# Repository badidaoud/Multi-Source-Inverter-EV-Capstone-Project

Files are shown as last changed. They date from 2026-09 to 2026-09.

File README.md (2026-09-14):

# Multi-Source Inverter (MSI) for Electric Vehicles

A senior capstone project (Ontario Tech University, Electrical Engineering, 2025 to 2026) that designs and prototypes a novel multi-source inverter: a single power electronics board that combines two DC inputs (for example a battery and a solar/auxiliary source) and drives a three-phase AC motor, without the extra switch count that typical multi-source topologies need.

**Team:** Emmanuel Ita, Jack Flann, Dorsheed Abdalla, Badi Daoud
**Project Coordinator:** Dr. Mohamed Z. Youssef, Ontario Tech University

> This repository is my personal, individually maintained record of a four-person team capstone. It documents the project in full and credits every teammate's contribution; it is not a claim of solo authorship. The team's original working repository, maintained by a teammate, is linked in [Attribution](#attribution-and-original-repository) below.

## Table of Contents

- [Problem Statement](#problem-statement)
- [Existing Solutions](#existing-solutions)
- [Project Objectives](#project-objectives)
- [Design Process](#design-process)
- [Proposed Design](#proposed-design)
- [Hardware and Schematics](#hardware-and-schematics)
- [Final Product](#final-product)
- [Video Demos](#video-demos)
- [Testing and Results](#testing-and-results)
- [Challenges and Root Cause Analysis](#challenges-and-root-cause-analysis)
- [My Contributions](#my-contributions)
- [Project Timeline](#project-timeline)
- [Repository Contents](#repository-contents)
- [Attribution and Original Repository](#attribution-and-original-repository)

## Problem Statement

Electric vehicle inverters today face real limits on efficiency, size, and flexibility:

- Most EV traction inverters run on a single DC source, which restricts controllability and limits adaptability across operating conditions.
- Efficiency drops significantly at partial loads, which is most of real-world driving, directly impacting vehicle range.
- Modern EV systems increasingly need to combine multiple DC sources (battery cells, PV modules, auxiliary supplies) and reconfigure them dynamically.
- Existing multi-source inverter (MSI) topologies in the literature solve this, but usually at the cost of high switch counts, added control circuitry, and a larger form factor.

The goal of this project was to design an MSI that keeps the benefits of multi-source operation (dynamic voltage combining, source flexibility) while cutting down the component count, board footprint, and cost that usually come with it.

## Existing Solutions

We reviewed the landscape before designing our own approach:

- Conventional 2-level and 3-level NPC inverters with a single DC input: good performance, but high switching losses and no source flexibility.
- PWM/SPWM control: simple and widely used, but DC-bus utilization tops out around 78% with significant harmonic distortion.
- SVPWM control: better DC-bus utilization (over 90%) and lower distortion, but still tied to a single fixed-voltage DC link.
- Two-input MSI topologies from the literature: allow dynamic voltage combining, but require many switches, which increases complexity, size, and cost.
- Source-combination strategies each have a tradeoff: parallel combination needs identical sources and limits voltage flexibility, series combination risks source imbalance and voltage jumps, and switched MSI structures add control complexity and don't scale well past two sources.

No market solution currently exists for this exact combination of goals; reconfigurable EV battery packs exist, but they switch a single battery system between series and parallel, not multiple independent sources into one inverter stage.

## Project Objectives

Six requirements, tied directly to the problem above, drove every design decision:

- Design a novel multi-source input stage
- Minimize component count
- Develop a PCB with a minimal footprint
- Meet safety requirements
- Meet a $800 budget
- Minimize harmonic distortion

## Design Process

We followed an iterative engineering workflow: problem definition, requirement specification, research on existing solutions, concept generation, PSIM simulation, conceptual system design, PCB layout, firmware design, and testing and evaluation, cycling back through simulation and system design as results came in.

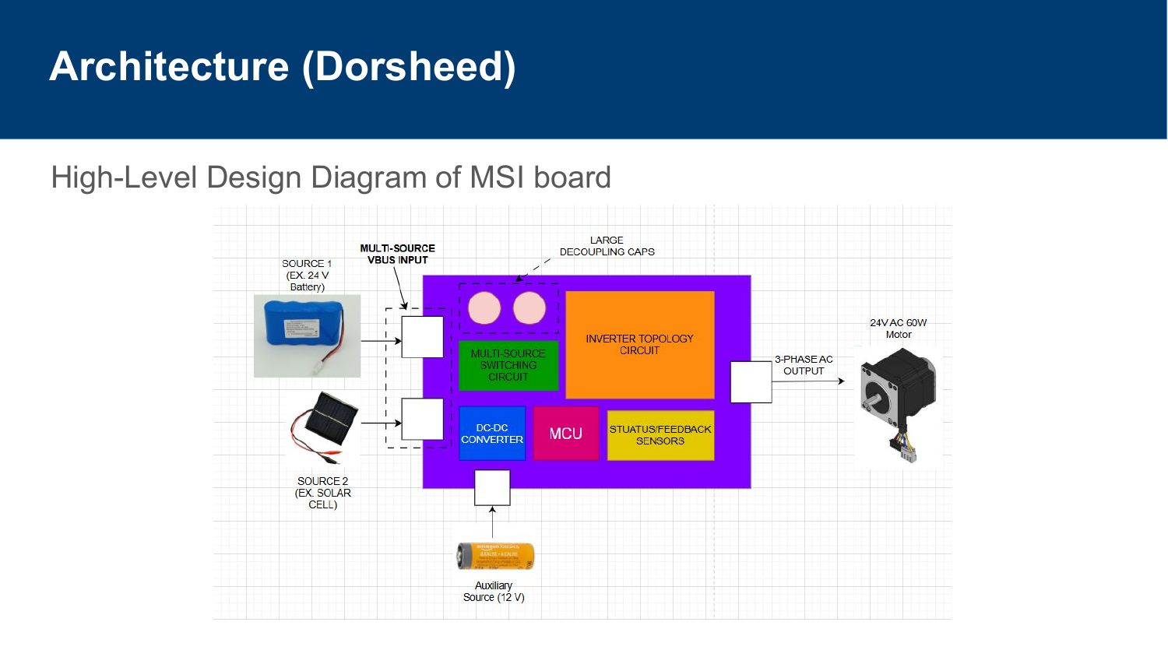
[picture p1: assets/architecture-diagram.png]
Design process flowchart

*High-level design diagram of the MSI board: two DC sources plus an auxiliary 12V supply feed a multi-source switching circuit and DC-DC converter, controlled by an STM32 MCU, driving a 2-level inverter topology out to a three-phase AC motor.*

Field-Oriented Control (FOC) was chosen as the motor control strategy: a closed-loop scheme that maximizes the motor's quadrature (rotational) force by continuously measuring output currents and rotor position and adjusting switching accordingly.

## Proposed Design

Our novel MSI design combines two DC battery inputs in parallel through a switched front end, which:

- Merges multiple DC inputs safely into a shared DC bus (12, 24, or 36V depending on configuration)
- Minimizes component count relative to literature MSI topologies
- Supports multiple voltage levels and can scale up toward a full-size system
- Uses diodes in the prototype (for a full-scale version, these would be replaced with actively controlled IGBTs or SiC MOSFETs)

The main design risks we identified going in were shoot-through during switching (which can cause extensive damage) and the need for tight current control during source-mode transitions, both of which turned out to matter later during hardware testing (see [Challenges and Root Cause Analysis](#challenges-and-root-cause-analysis)).

## Hardware and Schematics

The board is organized into six subsections: multi-source input switching, auxiliary input power, a DC-DC/voltage regulation stage, an STM32/ESP32-class microcontroller for control, a 2-level inverter topology stage (gate drivers plus MOSFETs), and feedback sensors (current, voltage, and speed sensing) for closed-loop control. The full KiCad source for each sheet below lives in [`hardware/kicad/`](hardware/kicad/); everything here was individually recreated in KiCad after the original board's PCB order came back defective (see [Challenges and Root Cause Analysis](#challenges-and-root-cause-analysis)).

<table>
<tr>
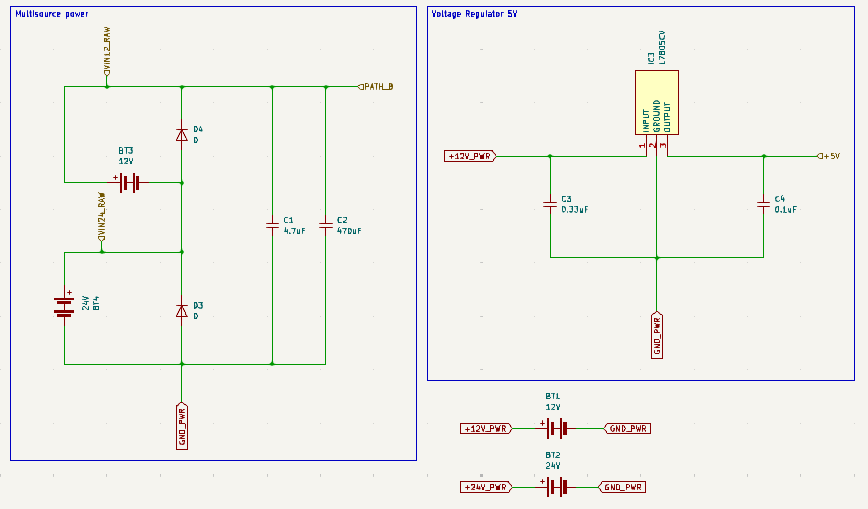
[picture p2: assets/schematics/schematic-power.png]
Multi-source power and 5V voltage regulator schematic
<td></td>
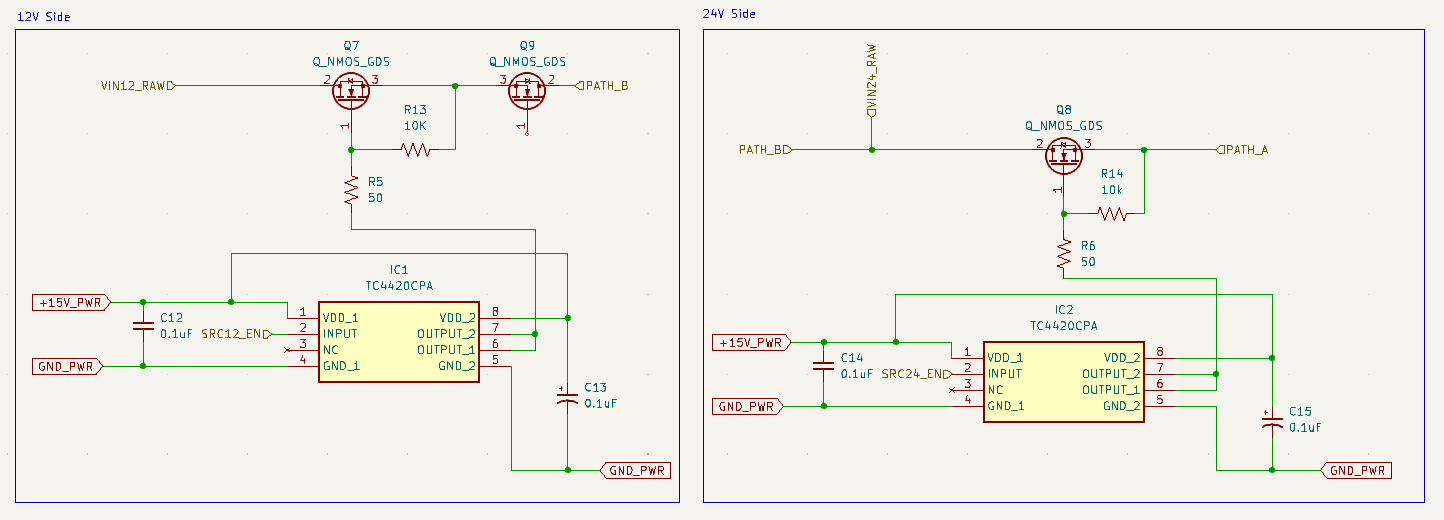
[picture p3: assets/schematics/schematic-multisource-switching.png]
Multi-source path switching schematic
<td></td>
</tr>
<tr>
<td align="center"><em>Power sheet: 12V/24V multi-source battery inputs and 5V linear regulator (<a href="hardware/kicad/Power.kicad_sch">Power.kicad_sch</a>)</em></td>
<td align="center"><em>Multi-source path switching (12V/24V side MOSFET switching into PATH_A/PATH_B). Source file for this sheet was not part of this export; screenshot only.</em></td>
</tr>
<tr>
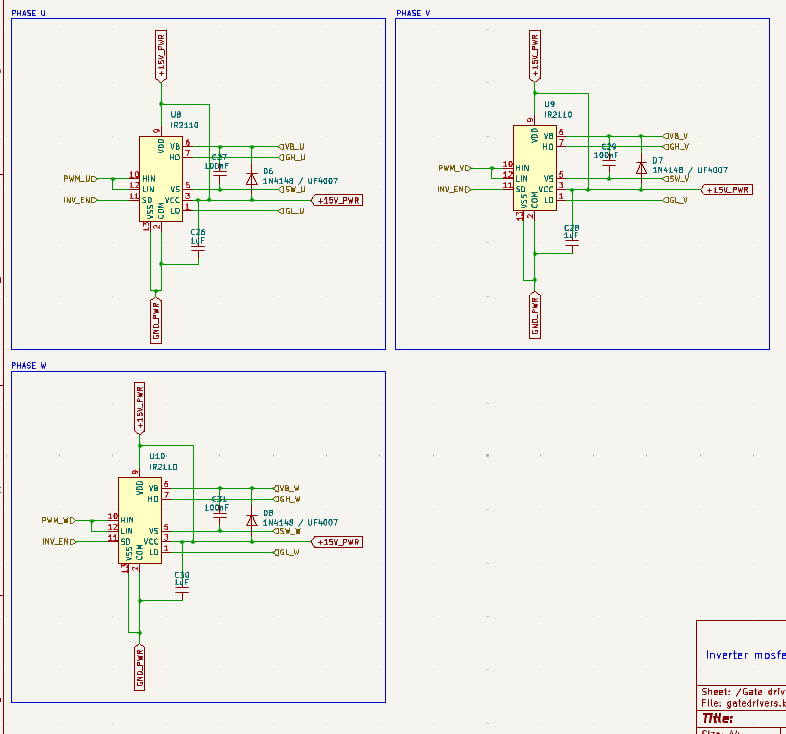
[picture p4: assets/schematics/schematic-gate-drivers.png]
Gate driver schematic
<td></td>
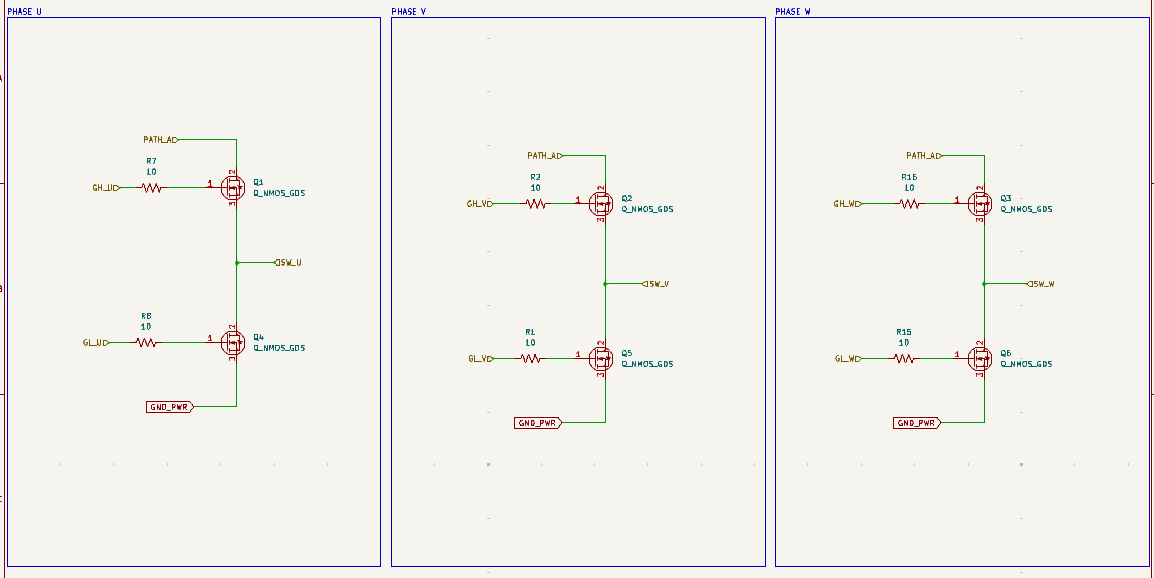
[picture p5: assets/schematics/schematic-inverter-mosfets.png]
Inverter MOSFET stage schematic
<td></td>
</tr>
<tr>
<td align="center"><em>Gate drivers: IR2110/IR2LLO high/low-side drivers per phase (<a href="hardware/kicad/gatedrivers.kicad_sch">gatedrivers.kicad_sch</a>)</em></td>
<td align="center"><em>2-level inverter MOSFET stage, phases U/V/W (<a href="hardware/kicad/inverters.kicad_sch">inverters.kicad_sch</a>)</em></td>
</tr>
<tr>
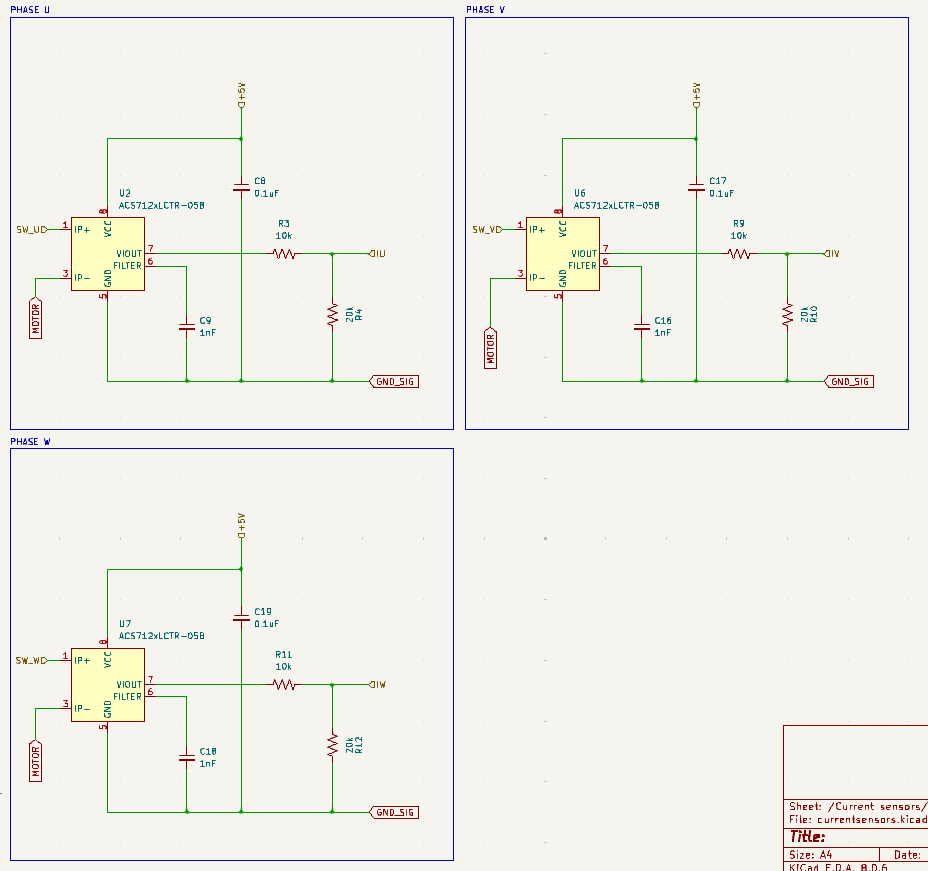
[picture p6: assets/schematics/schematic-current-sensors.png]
Current sensor schematic
<td></td>
<td>Motor connector schematic</td>
</tr>
<tr>
<td align="center"><em>Per-phase current sensing with ACS712 Hall-effect sensors (<a href="hardware/kicad/currentsensors.kicad_sch">currentsensors.kicad_sch</a>)</em></td>
<td align="center"><em>Motor output connector (<a href="hardware/kicad/motor.kicad_sch">motor.kicad_sch</a>)</em></td>
</tr>
</table>

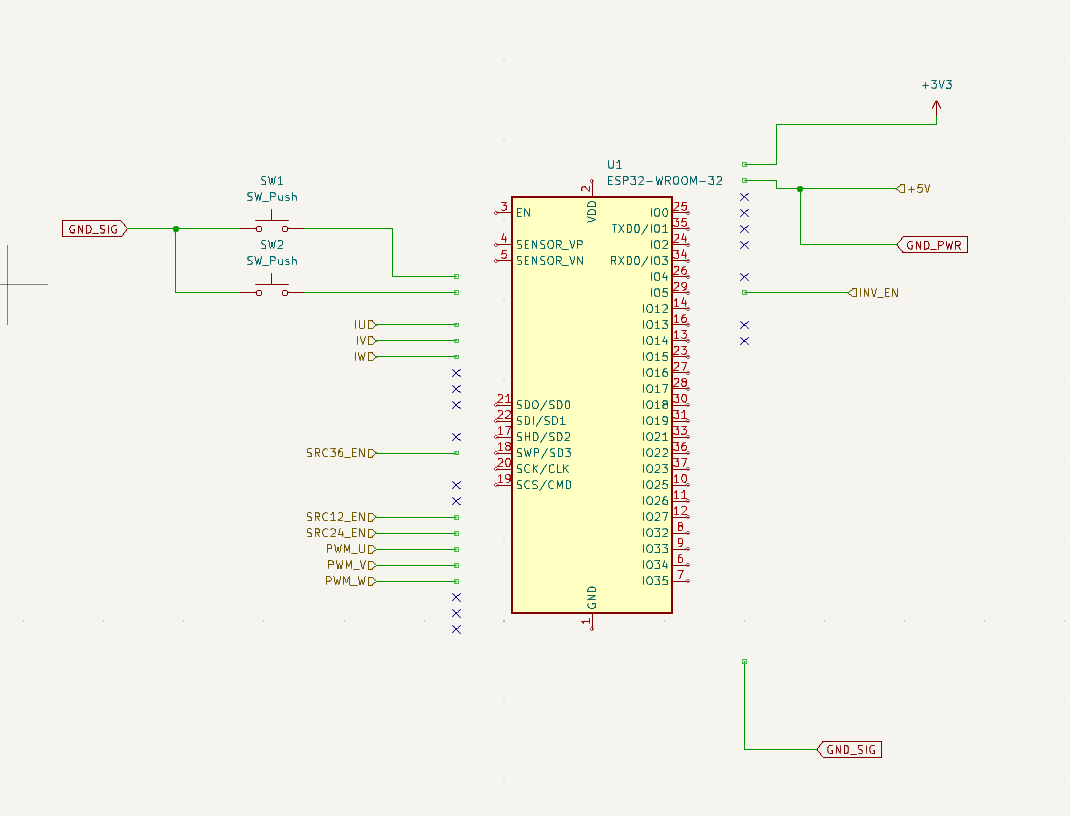
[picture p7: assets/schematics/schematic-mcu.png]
MCU schematic


*Microcontroller sheet (<a href="hardware/kicad/MCU.kicad_sch">MCU.kicad_sch</a>). This sheet was not finished by the end of the capstone; it's included as a work in progress, not a completed design.*

The top-level sheet tying everything together is [`hardware/kicad/MSI.kicad_sch`](hardware/kicad/MSI.kicad_sch). Note the PCB layout itself (copper routing, footprints) was not completed in KiCad due to time constraints; the [Final Product](#final-product) PCB images below are from the original Altium-based board.

Additional schematic sections (connectors, DC-DC converter details) are also captured slide-by-slide in the demo presentation under [`docs/presentations/`](docs/presentations/).

## Final Product

<table>
<tr>
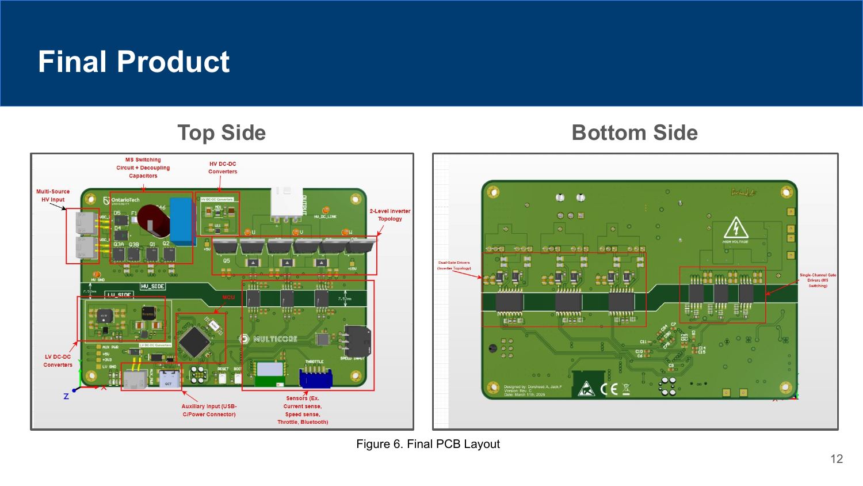
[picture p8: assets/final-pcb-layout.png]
Final PCB layout, top and bottom
<td></td>
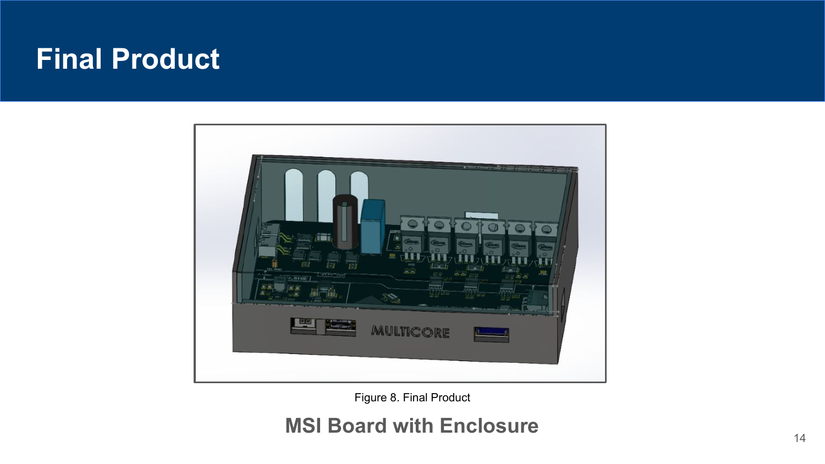
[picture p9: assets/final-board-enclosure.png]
Final MSI board with enclosure
<td></td>
</tr>
<tr>
<td align="center"><em>Final PCB layout (top and bottom copper)</em></td>
<td align="center"><em>Final board with enclosure, ready for demo</em></td>
</tr>
</table>

## Video Demos

<table>
<tr>
<td><a href="https://youtu.be/wHL-Usw2PE0">Capstone working demo video</a></td>
<td><a href="https://www.youtube.com/watch?v=NoywARZFs50">KiCad prototype walkthrough video</a></td>
</tr>
<tr>
<td align="center"><a href="https://youtu.be/wHL-Usw2PE0">Team capstone working demo</a></td>
<td align="center"><a href="https://www.youtube.com/watch?v=NoywARZFs50">My individual KiCad prototype walkthrough</a></td>
</tr>
</table>

## Testing and Results

Testing moved from individual component validation up to full integration:

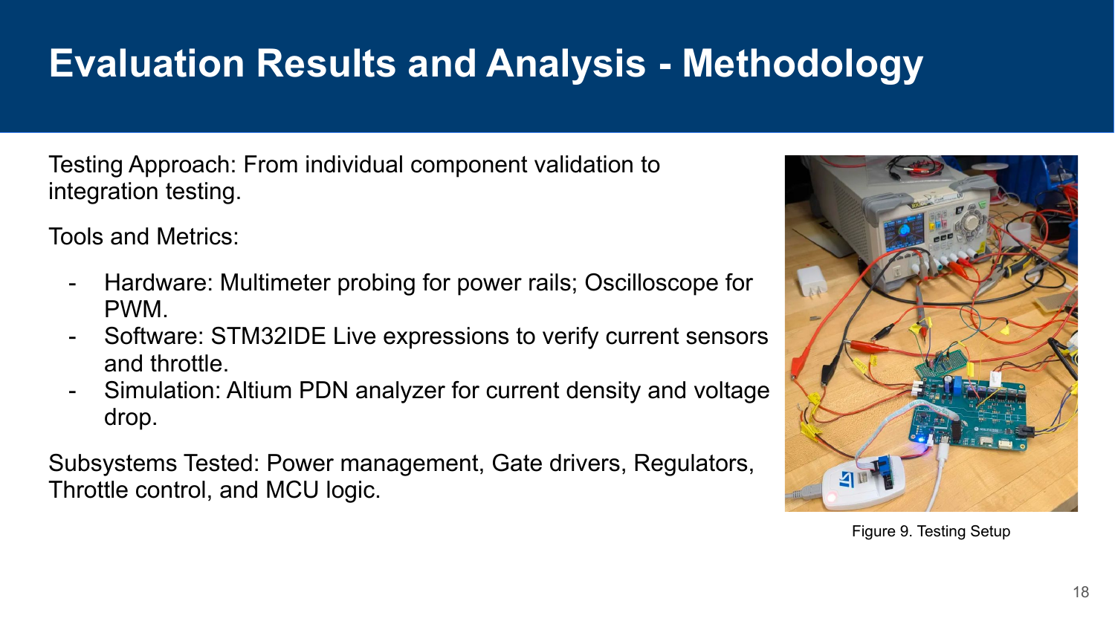
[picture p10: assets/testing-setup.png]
Testing setup

*Bench testing setup: multimeter probing on power rails, oscilloscope on PWM outputs, STM32IDE live expressions for current sensors and throttle, and Altium's PDN analyzer for current density and voltage drop in simulation.*

Being upfront about the outcome is part of the point of documenting this project:

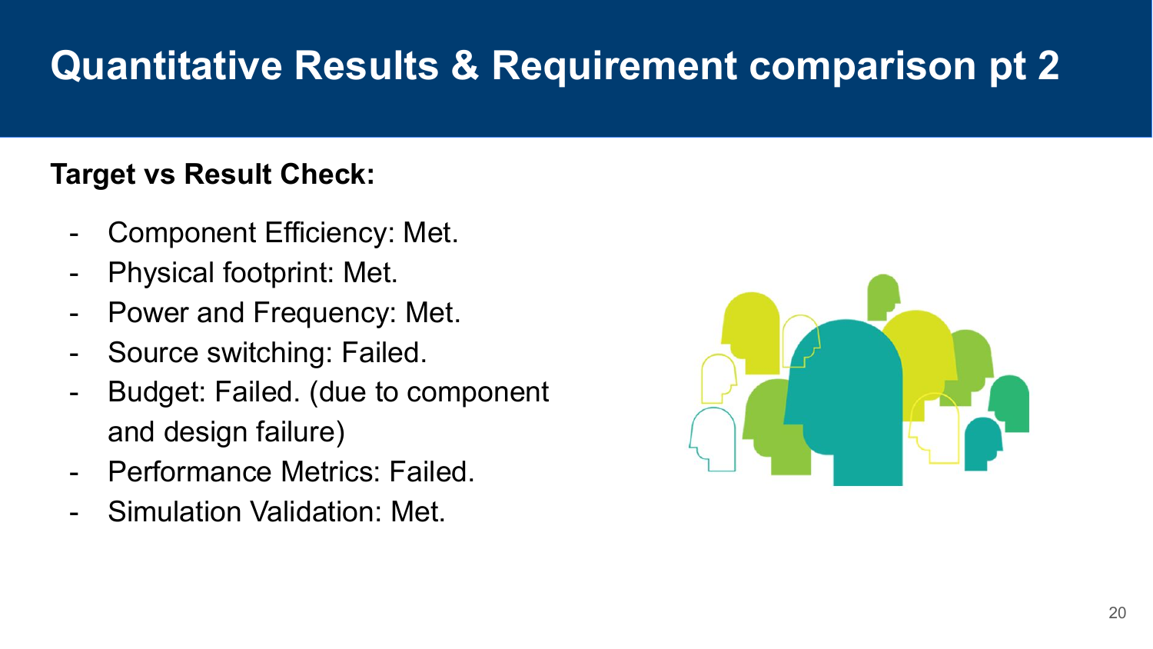
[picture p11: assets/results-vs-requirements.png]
Results versus requirements


| Requirement | Result |
|---|---|
| Component efficiency | Met |
| Physical footprint | Met |
| Power and frequency | Met |
| Simulation validation | Met |
| Source switching | Not met |
| Performance metrics | Not met |

**Note on source switching:** my individual KiCad prototype did successfully implement source switching. The "Not met" result above traces back to a routing error in the original PSIM schematic, which carried through to the team's final Altium design: the MOSFETs were not placed correctly relative to the routing, which prevented the final board from switching between sources.

## Challenges and Root Cause Analysis

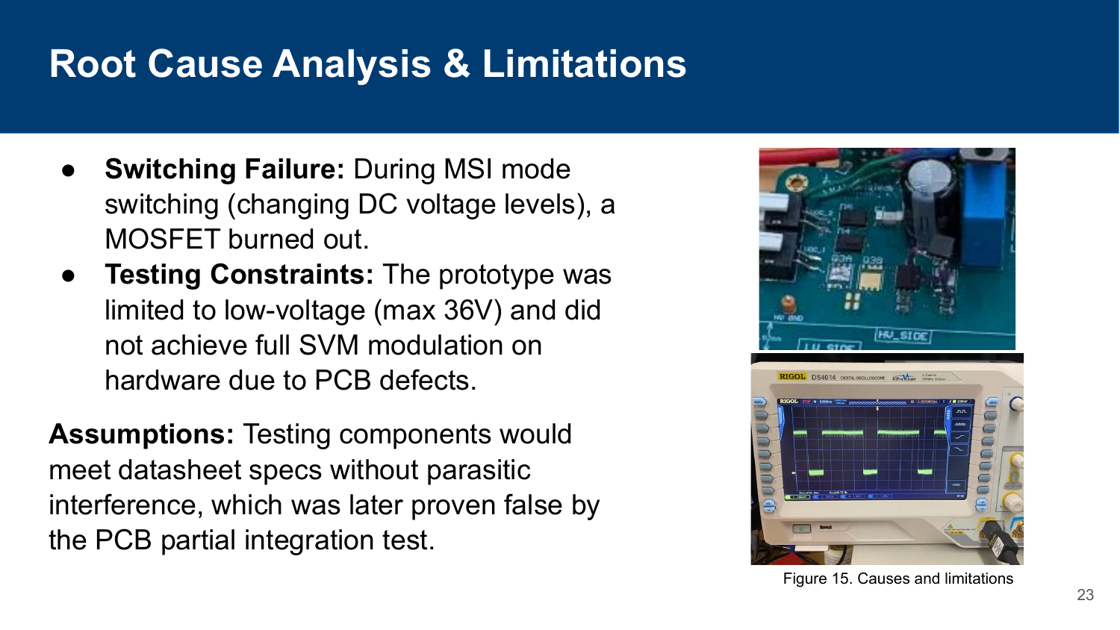
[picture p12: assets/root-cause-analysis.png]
Root cause analysis


The two biggest issues we ran into on hardware:

- **Switching failure:** during MSI mode switching (changing DC voltage levels), a MOSFET burned out. Our working assumption, that components would meet datasheet specs without parasitic interference, turned out to be false once we ran the partial integration test.
- **Testing constraints:** the prototype was limited to low voltage (36V max) and didn't reach full SVM modulation on hardware, because of PCB defects rather than a control-algorithm limitation.

We also worked through a PCB design defect, early Bluetooth/USB-C communication issues, a DC-DC converter fault, firmware bring-up, circuit shorts, and undersized fusing, upgrading from a 5A to a 10A fuse after the first hardware iteration.

## My Contributions

My individual work on the team covered:

- Owned and presented the **Project Timeline** section of the demo (see [`docs/presentations/`](docs/presentations/)) and contributed to the team's overall project management plan (see [Project Timeline](#project-timeline) below).
- When our ordered PCB arrived with a defect, rebuilt the schematic in KiCad after running into an Altium compatibility issue on my end.
- Diagnosed a missing back-EMF protection component as the root cause of a voltage-drop issue on the board.
- Worked around the faulty ordered board by bringing up control on a standalone STM32 dev board so testing and firmware validation could continue in parallel with the hardware fix.

The team placed 3rd at the Capstone Design Annual Exhibition, despite the working prototype not being fully functional at demo time, on the strength of the design, documentation, and root-cause analysis.

## Project Timeline

The project ran on a 12-phase plan from initiation in September 2025 through the Capstone Design Annual Exhibition. See [`docs/planning/`](docs/planning/) for the full team project management plan (exported from MS Project) alongside a condensed summary. Major phases:

| Phase | Start | Duration |
|---|---|---|
| Initiation & Scoping | Sep 8, 2025 | 14 days |
| Requirements & Planning | Sep 22, 2025 | 13 days |
| Simulation & R1 Report | Oct 5, 2025 | 6 days |
| Conceptual Design & R2 Report | Oct 10, 2025 | 22 days |
| Prototyping & Presentation (Demo) | Nov 1, 2025 | 21 days |
| Team Retrospective Report | Nov 22, 2025 | 11 days |
| Preparations for Prototype | Dec 2, 2025 | 30 days |
| Prototype Development | Jan 5, 2026 | 36 days |
| Design and Testing Report | Jan 26, 2026 | 19 days |
| Acceptance Testing Report | Feb 9, 2026 | 26 days |
| Team Presentation & Video Clip | Mar 9, 2026 | 15 days |
| Final Engineering Report | Mar 13, 2026 | 8 days |
| Capstone Design Annual Exhibition | Mar 16, 2026 | 12 days |

## Repository Contents

```
.
├── README.md
├── assets/                      Figures used in this README
│   └── schematics/               Per-sheet schematic screenshots
├── hardware/
│   └── kicad/                    KiCad source (.kicad_sch), recreated after the original PCB order
│                                  came back defective. No PCB layout (.kicad_pcb) yet.
└── docs/
    ├── presentations/
    │   ├── Capstone-Demo-Presentation.pdf     Mid-project demo deck
    │   └── Capstone-Final-Presentation.pdf    Final results and demo deck
    └── planning/
        ├── Project-Management-Plan-Full.pdf       Detailed Gantt chart (initiation through demo)
        ├── Project-Management-Plan-Summary.pdf    Full-year phase summary
        └── Project-Management-Plan-Sections.pdf    Mid-project planning excerpt
```

The multi-source path-switching sheet and PSIM simulation files, plus the original Altium PCB layout, live in the team's original repository and may be added here over time as a personal archive.

## Attribution and Original Repository

This was a four-person team capstone project for Ontario Tech University, supervised by Dr. Mohamed Z. Youssef. The team's active working repository, including full source and design files, is maintained by teammate Dorsheed Abdalla:

**[github.com/dorsheed455k/MSI-Capstone](https://github.com/dorsheed455k/MSI-Capstone)**

This repository exists as my own record of the project and my contributions to it, built from the presentations and project management documentation I have on hand.

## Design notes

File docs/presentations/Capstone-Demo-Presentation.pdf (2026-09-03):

# Multi Source Inverter for

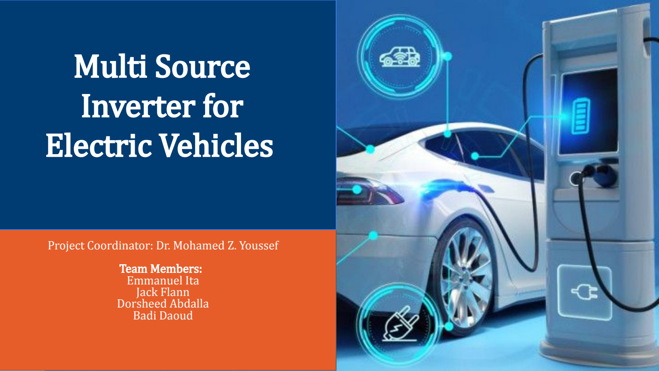
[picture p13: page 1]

### Project Coordinator: Dr. Mohamed Z. Youssef

### Team Members: Emmanuel Ita Jack Flann Dorsheed Abdalla Badi Daoud

# Electric Vehicles

# Overview (Dorsheed)

➔ | Problem Statement
➔ | Design Process
➔ | Architecture
➔ | Budget & Resource Requirements
➔ | Schematic and PCB Capture
➔ | Evaluation Results & Analysis
➔ | Project Timeline
➔ | Future Work & Conclusion
➔ | Demonstration

# Problem Statement (Dorsheed)

- EV inverters today face limitations in power loss, component count, size, and efficiency, especially under variable load and

multi-source operation.

- Existing EV traction inverters typical use a single DC source, which restricts controllability, increases switching losses, and limits

adaptability to different operating conditions.

- Modern EV systems require the ability to combine multiple DC sources (e.g., battery cells, PV modules) and dynamically

reconfigure them to improve performance and reliability.

- Current MSI topologies are complex, often requiring high switch counts, added control circuitry, and larger form factor. The goal

of this project is to reduce component count while retaining full functionality.

# Problem Statement (Dorsheed)

Main design requirements for the project for an efficient MSI:

- Merges multiple DC inputs safely
- Delivers stable three-phase AC output
- Minimize switching losses & harmonics
- Remains feasible for prototype implementation within academic constraints

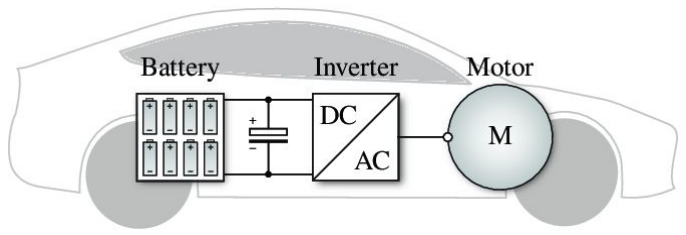
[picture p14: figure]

# Current Solutions (Dorsheed)

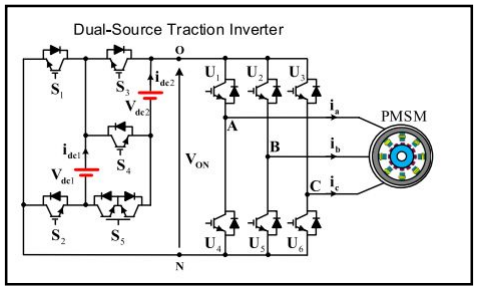
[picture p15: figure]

- Conventional EV traction inverters use 2-level or 3-level NPC topologies with single DC inputs; they offer good performance but suffer from high switching losses, limited voltage flexibility, and larger
component count.
- PWM/SPWM-controlled inverters are simple and widely used, but have low DC-bus utilization (~78%) and generate significant harmonics
- SVPWM-based inverters improve DC-bus utilization (>90%) and reduce harmonic distortion but still rely on fixed-voltage DC links and single-source architectures.
- Multi-Source inverter topologies from literature allow 2-input dynamic voltage combining but require many switches, increasing complexity, size, and cost.

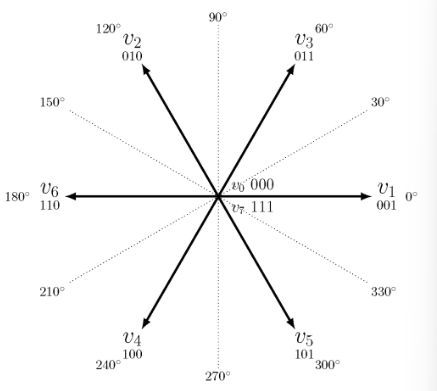
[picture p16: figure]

- Existing source-combination methods (parallel, series, switching networks) each present drawbacks:
- Parallel → requires identical sources; limited voltage flexibility.
- Series → introduces risk of source imbalance and voltage jumps.
- Switched MSI structures → high control complexity and limited scalability beyond two sources.

# Current Solutions

Field Oriented Control (FOC)

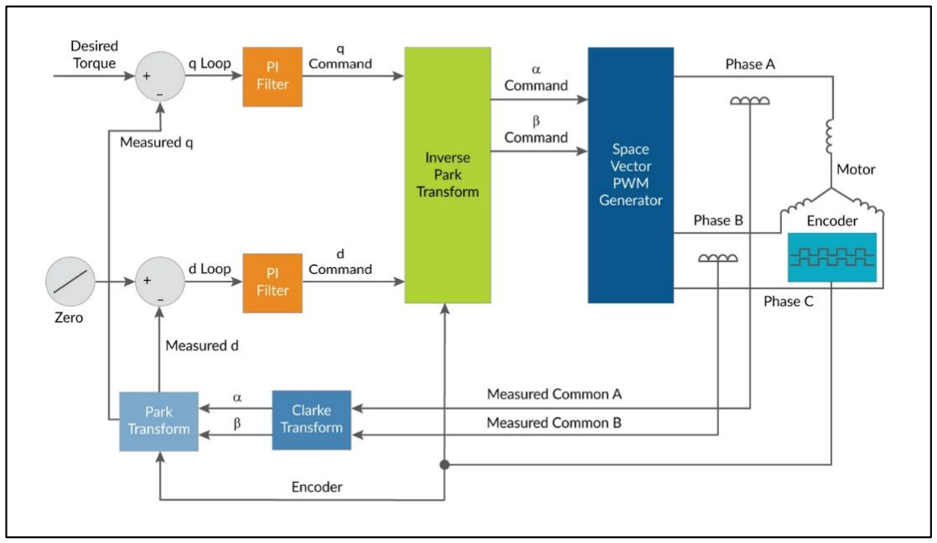
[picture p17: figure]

- FOC is a closed loop control system which aims to maximize the quadrature force (rotational force) of the motor.
- Measures output currents and motor position to continuously adjusting the switching

# Design Process (Emmanuel)

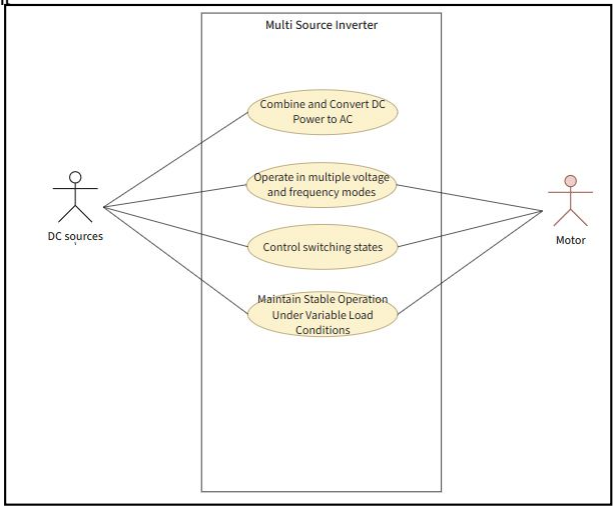
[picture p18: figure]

- Iterative engineering workflow based on research → simulation → refinement → hardware prototyping.
- Requirements gathering & stakeholder alignment performed early to define performance, size, cost, and compatibility objectives.
- Concept generation phase comparing inverter topologies, control methods (PWM/SPWM/SVM), switching devices (IGBT vs MOSFET vs SiC), and source-combination schemes.
- Field oriented control is the primary control method used in maximizing the rotational force of the motor
- PSIM simulation development to validate switching behavior, losses, controllability, and waveform quality before hardware implementation.
- Conceptual system design including subsystem breakdown: power management, filtering, MCU control, gate drivers, switching devices, and AC output.
- Integration & testing planning using defined test cases to verify source management, controller behavior, power regulation, safety, and performance.
- Prototype development phase to transition from simulation to PCB design, component selection, assembly, and final validation.

# Architecture (Dorsheed)

# High-Level Design Diagram of MSI board

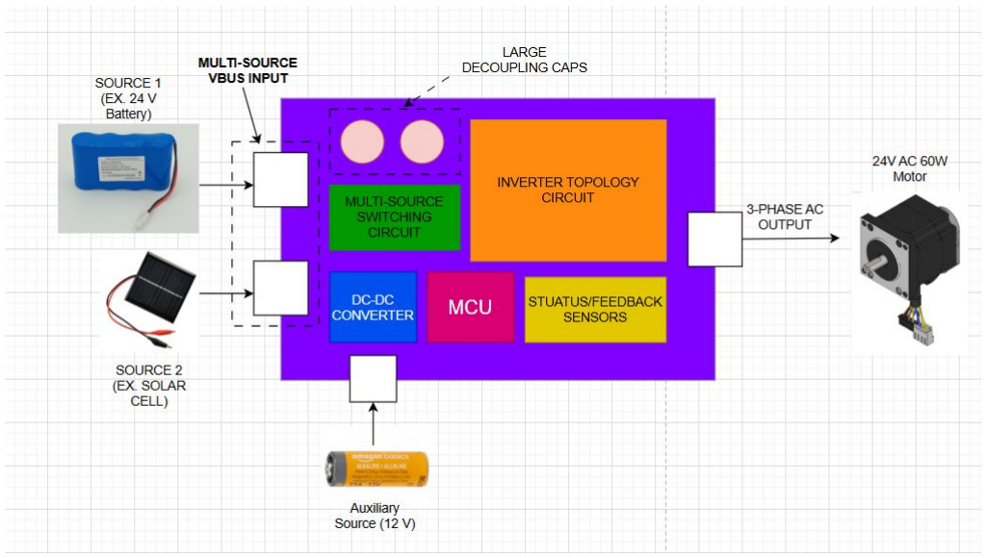
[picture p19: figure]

# Architecture (Dorsheed)

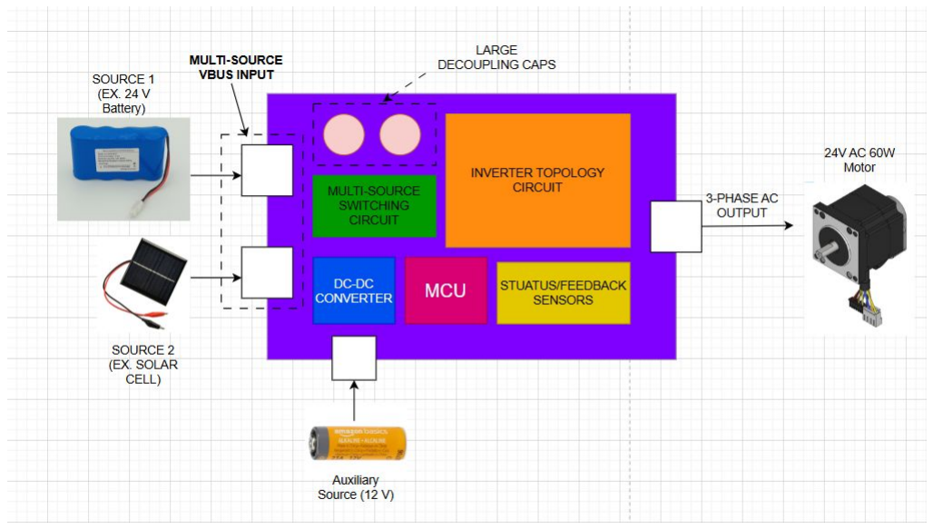
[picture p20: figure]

## Device Subsections

## 1. Multi-Source Input Section 2. Auxiliary Input Power 3. DC-DC Converter 4. MCU 5. Inverter Topology Circuit 6. Feedback Sensors

# Budget & Resource Requirements (Emmanuel)

Materials | Cost per unit($) | Quantity | Total Cost ($)
Motor | 109.33 | 1 | 109.33
DC Decoupling Caps | ~6 | 2 | 12
Ceramic Decoupling | ~6 | 1 | 6
All Resistors | - | - | 6
All Diodes | - | - | 6
MOSFETs | ~10.00 | 6 | 60.00
STM32G491VET6 board | 35.26 | 1 | 35.26
18650 li-ion battery | ~17.00 | 1 | 17.00
INA240A sensor | 3.23 | 2 | 6.46

# Budget & Resource Requirements (Emmanuel)

Materials | Cost per unit($) | Quantity | Total Cost ($)
Current Shunt | ~2.5 | 1 | 2.5
Heat sink | ~10 | 1 | 10
24-12V DCDC | ~7.5 | 1 | 7.5
24-5V DCDC | ~4 | 1 | 4
24-3.3V DCDC | ~4 | 1 | 4
PCB Fabrication | ~80 | 1 | 80
Cables & Connectors (Molex, wiring, terminal blocks) | ~20 | - | 20
Isolation, Fuses, Fuse Holders | ~10 | - | 10
Debug Hardware | ~15 | 1 | 15

# Budget & Resource Requirements (Emmanuel)

## Manpower Costs

Materials | Cost per unit($) | Quantity | Total Cost ($)
Assembly, Solder, Prototype Expenses | ~50 | - | 50
Total | | | 461.05
No. of team members | Hours per week | Salary per hour | No. of weeks in school year | Total ($)
4 | 7.25 | 30.71 | 24 | 21,374.16

# Simulation

# Evaluation Results & Analysis

# Project Timeline (Badi)

5 | Prototyping & Presentation | Nov. 26th 25'
5.1 5.2 | Hardware prototype development Nov. 1st 25' Nov. 18th 25' Team Presentation & Demo Nov. 19th 25' Nov. 26th 25'
6 | Team Retrospective Report | Dec. 2nd 25'
6.1 | Develop Report Nov. 22nd 25' Dec. 2nd 25'
7 | Preparations for prototype | Jan. 5th 26'
7.1 | Place orders on components and meet with advisor for PCB design analysis Dec. 2nd 25' Jan. 5th 26'
8 | Prototype Development | N/A
8.1 8.2 | Build prototype Week 1 Week 4 Conduct Integration testing Week 3 Week 6

# Schematic Showcase - Block Section

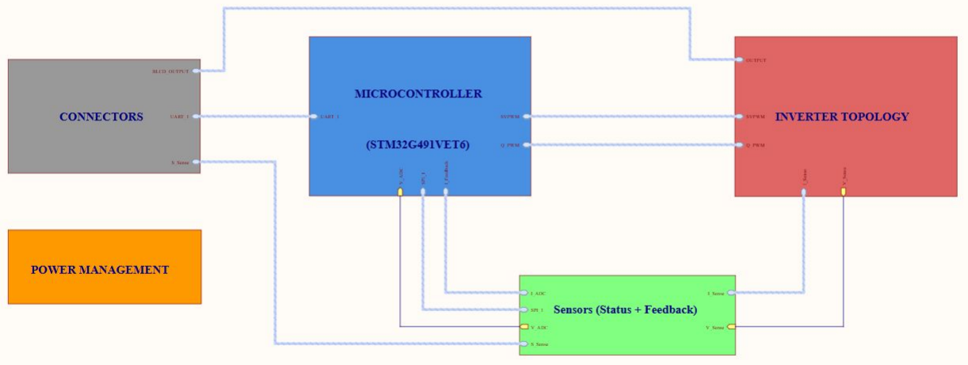
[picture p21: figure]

# Schematic Showcase - Microcontroller Section

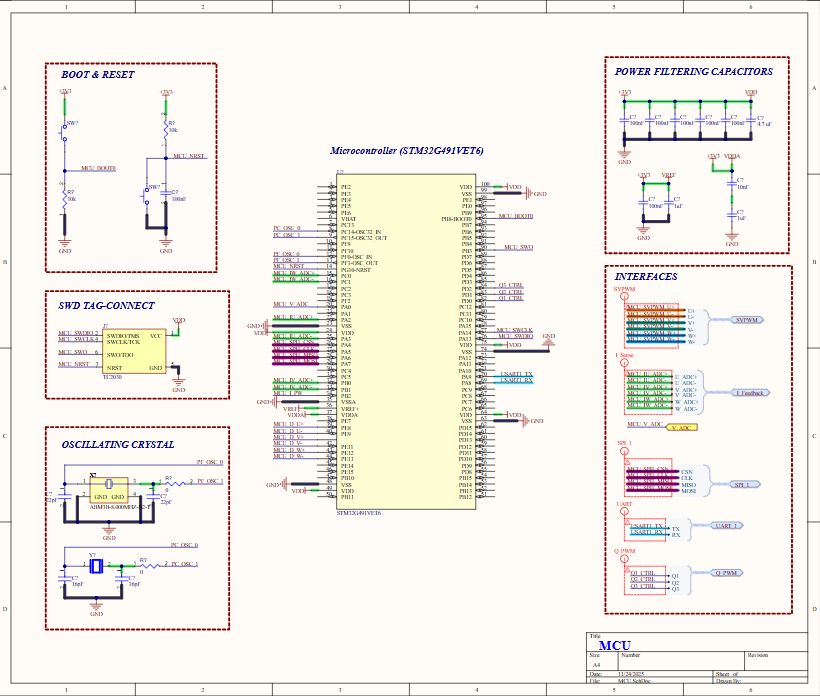
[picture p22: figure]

# Schematic Showcase - Inverter Topology Section

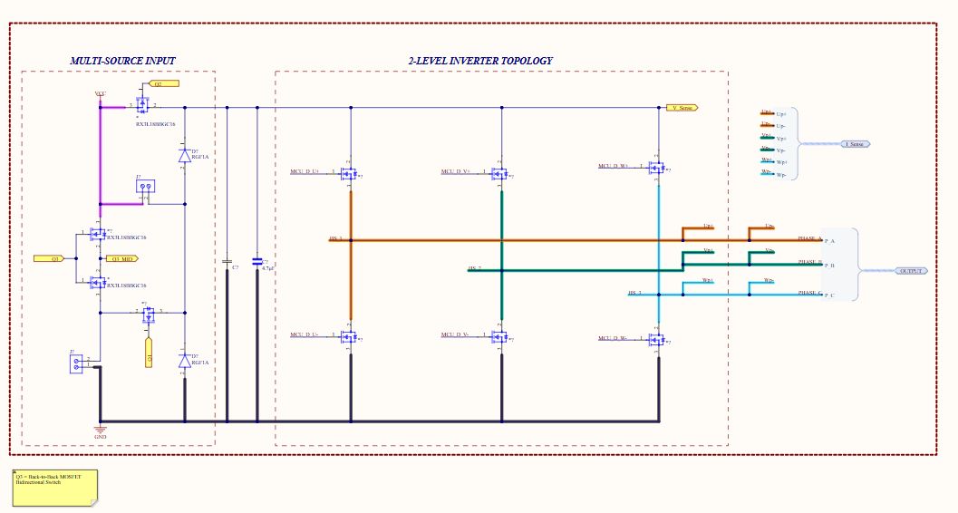
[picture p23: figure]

# Schematic Showcase - Connectors Section

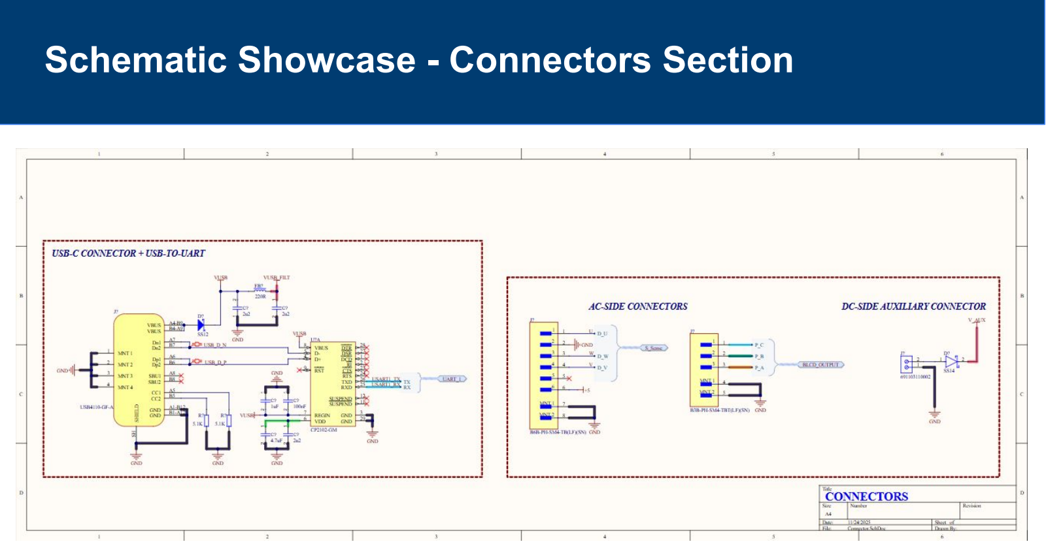
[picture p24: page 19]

# Schematic Showcase: DC-DC Converter Section

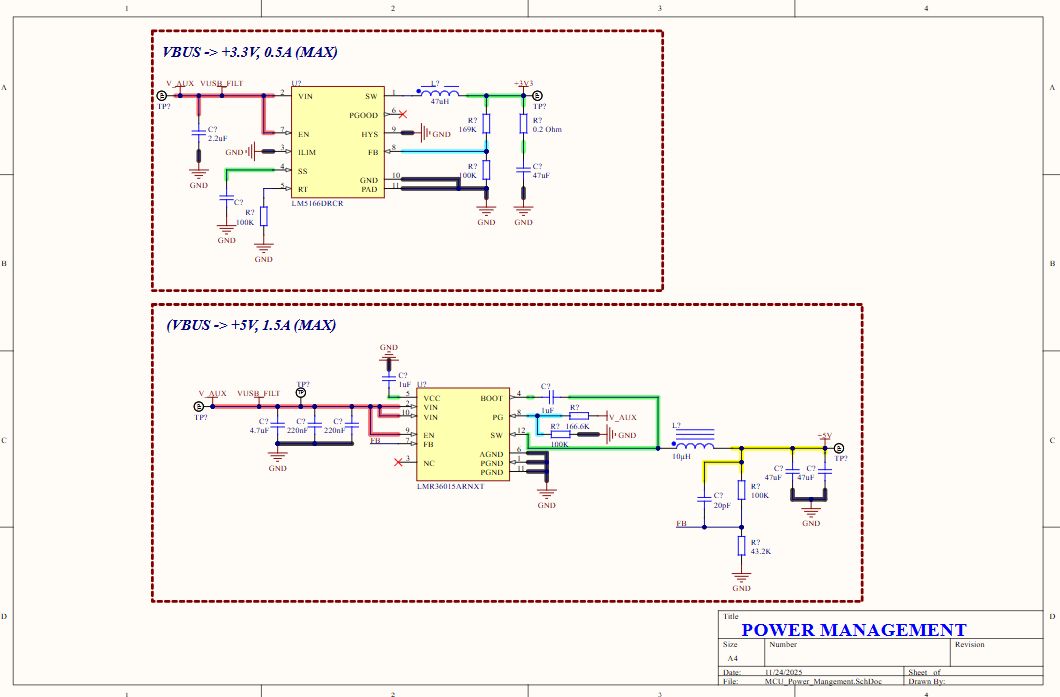
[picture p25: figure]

# Schematic Showcase: Sensor Circuit Section

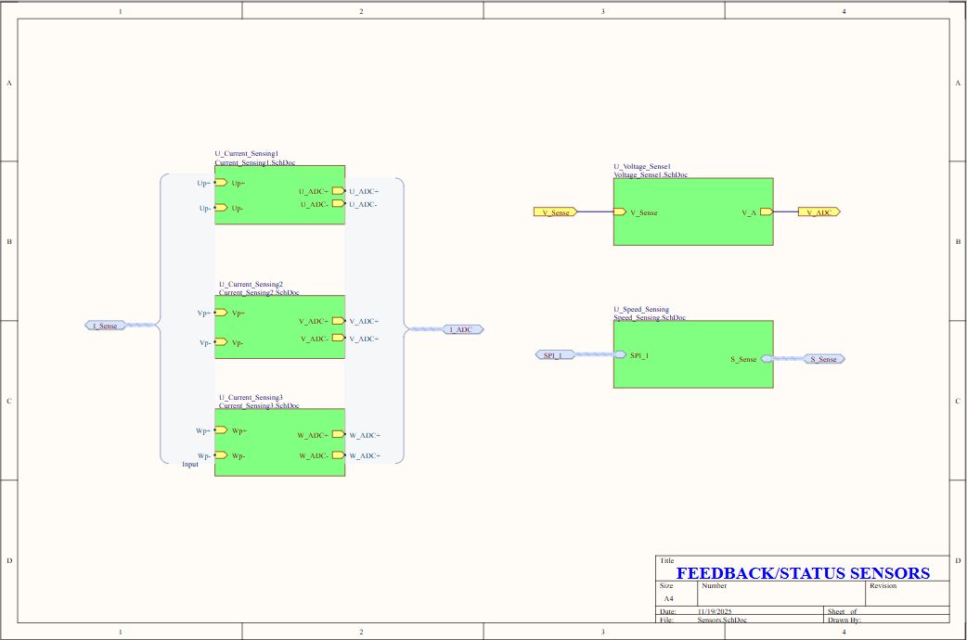
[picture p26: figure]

# 3D PCB View Showcase

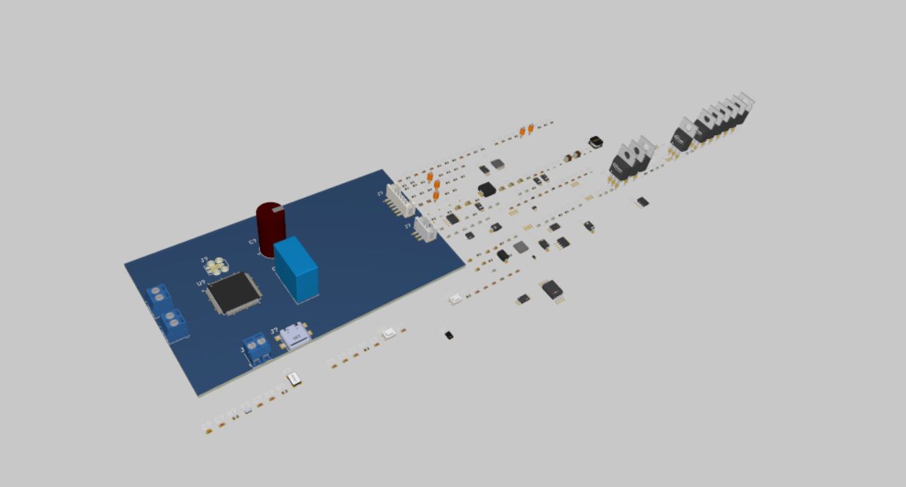
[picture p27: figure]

# Future Work & Conclusion (Dorsheed-Badi)

Q&A

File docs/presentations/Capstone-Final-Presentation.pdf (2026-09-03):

# Novel Multi Source Inverter for

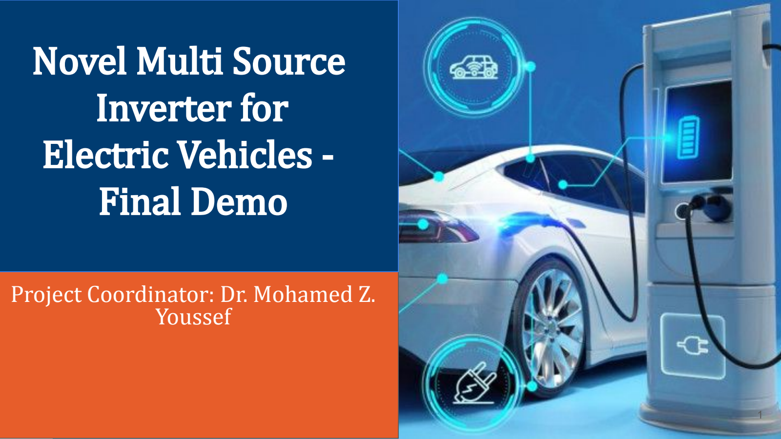
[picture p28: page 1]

Project Coordinator: Dr. Mohamed Z.

# Youssef

# Electric Vehicles -Final Demo

# Overview

1. Introduction
2. Problem Statement
3. Existing Solutions
4. Project Objectives
5. Design Process
6. Proposed Solution
7. Final Product
8. Budget & Resource Requirements
9. Evaluation Results & Analysis
10. Testing Approach
11. Q&A

# Introduction

- Growing demand for efficient EV power electronics in the last decade
- Limitations of current inverters:
1. Single DC source => limited flexibility
2. High switching losses & harmonics
3. Large size / high component count
- Trend toward multi-source energy systems in EVs, needed for smarter, more adaptable inverter designs
- Our solution: Novel Multi-Source Inverter (MSI)
- Combines multiple DC inputs
- Improves efficiency & performance
- Reduces complexity and size

# Problem Statement, Existing Solutions, Project Objectives

# Problem Statement

## - EV inverters don’t operate at peak efficiency across all load conditions

## - Efficiency drops significantly at partial loads (which is most real-world driving)

## - This directly impacts vehicle range and energy utilization

## - Most EVs rely on a single battery pack as the DC source

## - Limited flexibility in how power is delivered to the motor

## - Cannot adapt voltage/current dynamically to optimize efficiency

## - Forces the inverter to handle a wide operating range inefficiently

# Existing Solutions

Current Solutions in the Market:

- No current market solution exists, however this is a very active area of EV research.
- Reconfigurable batteries exist, but is used as a single battery system that dynamically switches from series and parallel cells.
- Existing designs require many switches, leading to more complexity, and increased cost.
- Our project aims to develop a solution that maintains the benefit of multi-source inverters, while reducing component count and complexity.

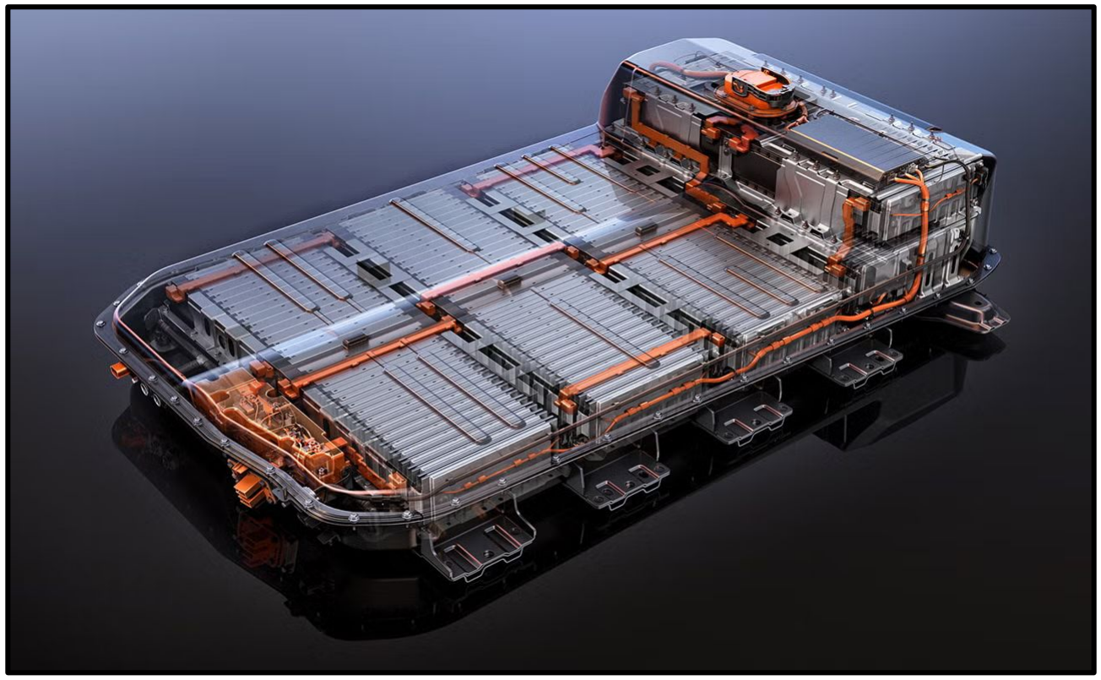
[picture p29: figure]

Figure 1. Modern EV Battery System

# Project Objectives

Our project objectives are closely tied to our

requirements.

- Minimize component count
- Develop a PCB with a minimal footprint
- Design a novel multi-source input
- Meet safety requirements
- Meet budget requirement of $800
- Minimize harmonic distortion

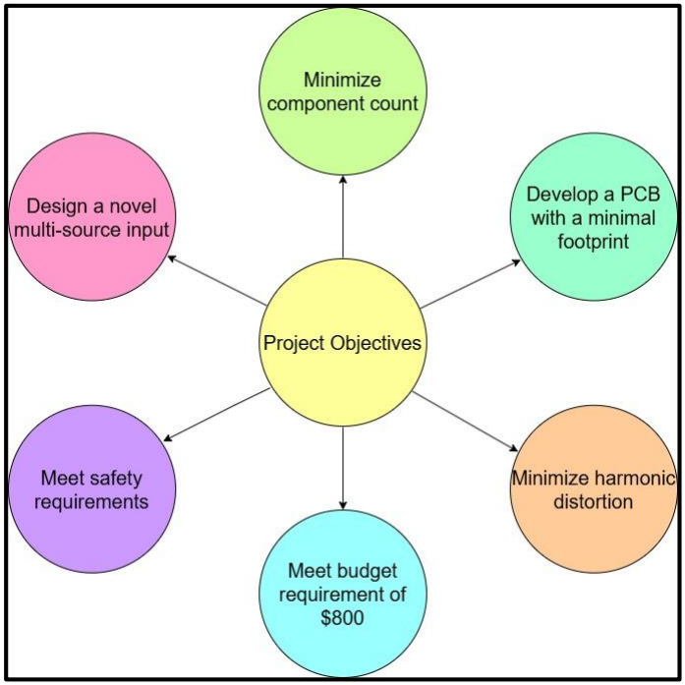
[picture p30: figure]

Figure 2. Project Objectives

# Engineering Design

# Design Process

- Iterative engineering workflow
- Problem Definition
- Requirement Specification
- Research
- Concept generation
- Simulations
- Conceptual system Design
- PCB Layout
- Firmware Design
- Testing and Evaluation

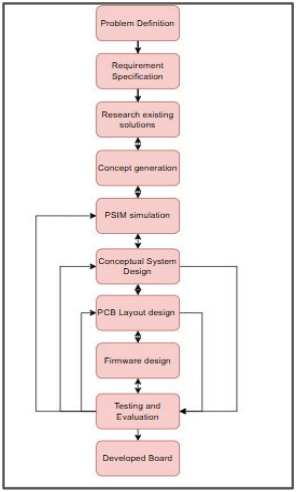
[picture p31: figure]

Figure 3. Design Process | 9

# Proposed Solution - Novel Design

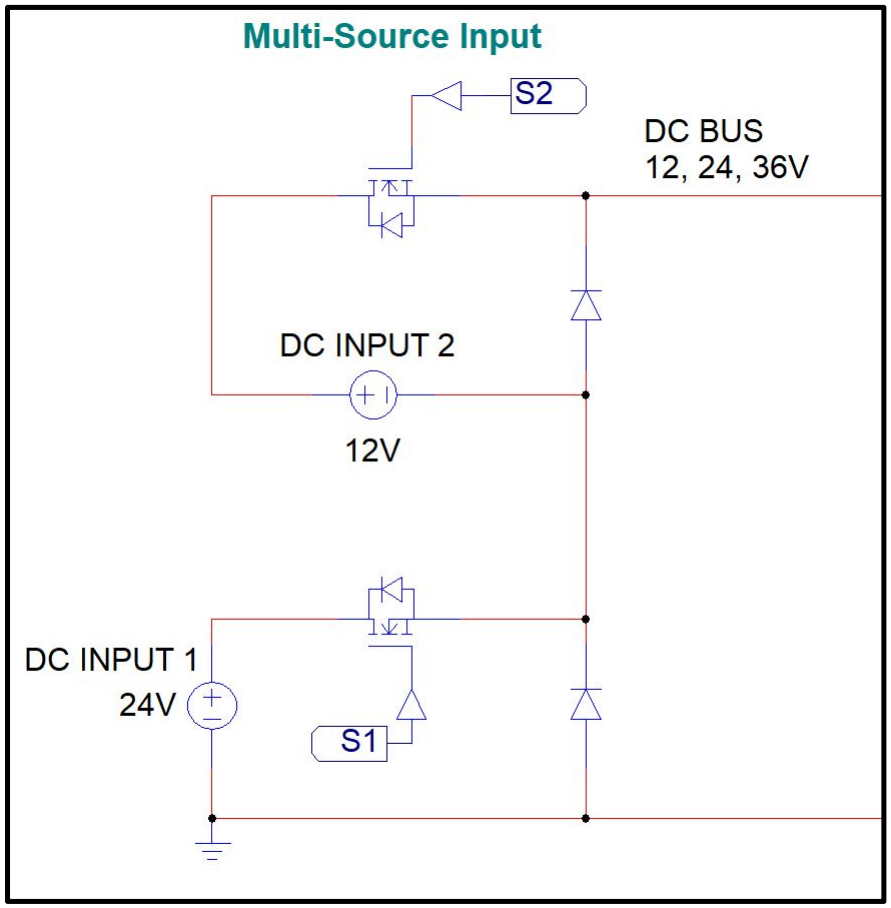
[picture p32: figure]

Figure 4. Novel MSI Design

MSI Novel Design:

- Two battery inputs
- Parallel design
- Minimized component count
- Multiple voltage levels
- Can be scaled to full size system
- Application adjustments can be made

Challenges and Concerns:

- In a full scale model, diodes can be replaced with

IGBT/SiC MOSFETs for active control

- Shoot-through can cause extensive damage
- Current needs to be controlled when switching

modes

# Proposed Solution - Novel Design

Proposed Solution: Multi-Source Inverter (MSI)

- Integrates multiple DC inputs into one system

Key architecture blocks:
- Multi-source input switching
- DC-DC regulation stage
- STM32 MCU (control + PWM)
- 3-phase inverter topology
- Feedback sensors (closed-loop control)

Key design goals:
- Dynamic source selection
- Improved efficiency (low & high speed)
- Reduced component count
- Modular & scalable architecture

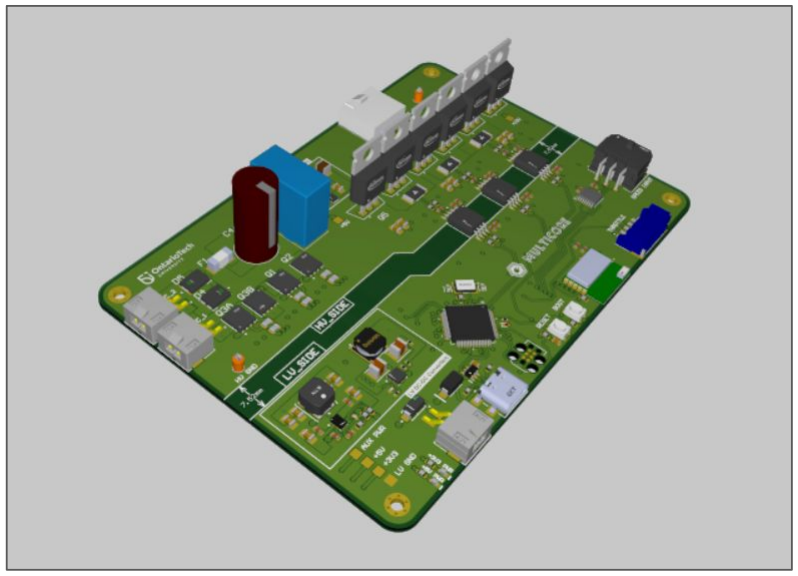
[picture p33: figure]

Figure 5. Final Design Solution

# Final Product

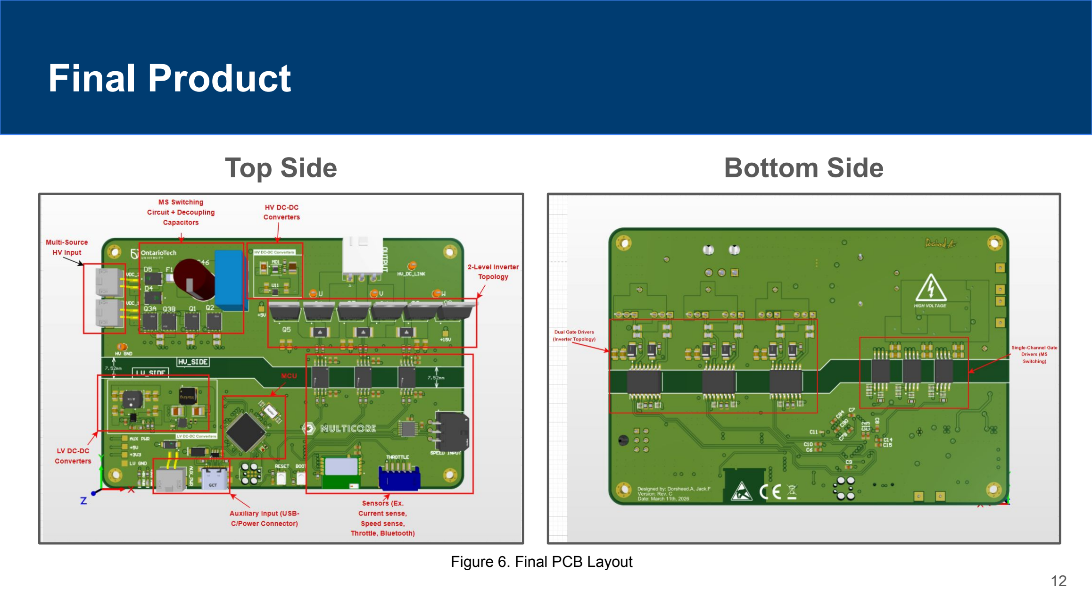
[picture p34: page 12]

Top Side | Bottom Side

Figure 6. Final PCB Layout

# Final Product

Power Delivery Simulation | Assembled Board

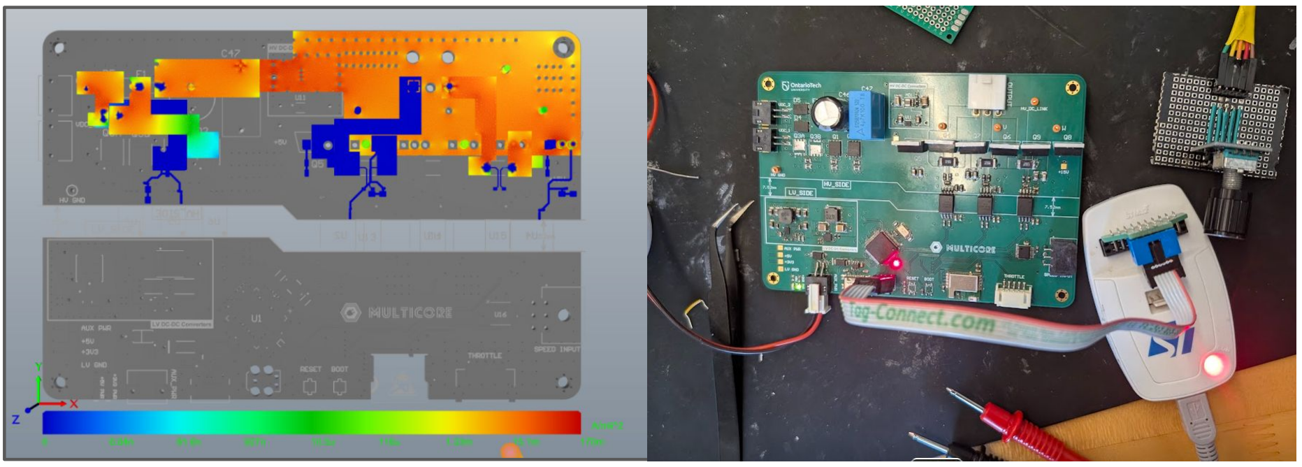
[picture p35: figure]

Figure 7. Final Product

# Final Product

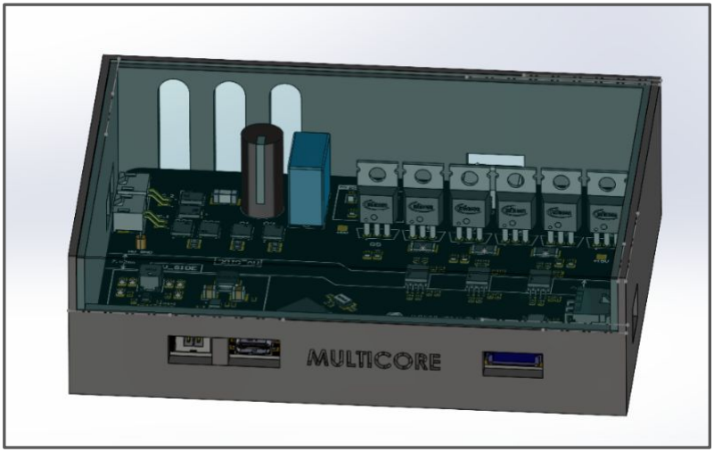
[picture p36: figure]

## MSI Board with Enclosure

Figure 8. Final Product

# Estimated Project Budget

## The table below highlights estimated budget of key materials for our project

Materials | Cost per unit($) | Quantity | Total Cost ($)
Motor | 109.33 | 1 | 109.33
MOSFETS | 10.00 | 6 | 60.00
PCB Fabrication | 80.00 | 1 | 80.00
18650 li-on battery | 17.00 | 1 | 17.00
STM32G491VET6 board | 35.26 | 1 | 35.26
Most PCB components | | | 159.46
Total | | | 461.05

# Actual Project Budget

Materials | Cost per unit($) | Quantity | Total Cost ($)
Motor | 73.56 | 1 | 73.56
PCB Fabrication | 66.49 | 3 | 199.47
Batteries(12V and 24V | 94.13 | 1 | 94.13
Most PCB components | | | 489.61
Total | | | 856.77

# Analysis & Testing

# Evaluation Results and Analysis - Methodology

### Testing Approach: From individual component validation to

integration testing.

### Tools and Metrics:

### - Hardware: Multimeter probing for power rails; Oscilloscope for

PWM.

### - Software: STM32IDE Live expressions to verify current sensors

and throttle.

### - Simulation: Altium PDN analyzer for current density and voltage

drop.

Subsystems Tested: Power management, Gate drivers, Regulators, Throttle control, and MCU logic.


Figure 9. Testing Setup

# Quantitative Results & Requirement comparison

## - PWM Performance


## - PDN Analysis - Physical Design

Figure 10. PCB Testing | 19

# Quantitative Results & Requirement comparison pt 2

## Target vs Result Check:

- Component Efficiency: Met.


- Physical footprint: Met.
- Power and Frequency: Met.
- Source switching: Failed.

## - Budget: Failed. (due to component and design failure)

- Performance Metrics: Failed.
- Simulation Validation: Met.

Challenges & Solutions; Challenges:; 1. PCB Design Defect 2. Communication Blockers 3. DC-DC Converter 4. Firmware implementation 5. Shorts in the circuit 6. 5A Fuse; Figure 11. PCB Defect; Figure 12. DCDC Converter

Figure 13. USB-C and Bluetooth | Figure 14. Fuse

# Challenges & Solutions pt 2


## Solutions:

## 1. Fixing design 2. Using STM32 STLINK


## 3. Voltage Regulator replacement


## 4. Cursor aided in fixing errors 5. Fixed excess solder 6. 10A Fuse


Figure 14. Solutions

# Root Cause Analysis & Limitations

## - Switching Failure: During MSI mode switching (changing DC voltage levels), a

MOSFET burned out.

## - Testing Constraints: The prototype was limited to low-voltage (max 36V) and did not achieve full SVM modulation on

hardware due to PCB defects.

## Assumptions: Testing components would meet datasheet specs without parasitic interference, which was later proven false by

the PCB partial integration test.


Figure 15. Causes and limitations

# Conclusion & Future Work


Q&A


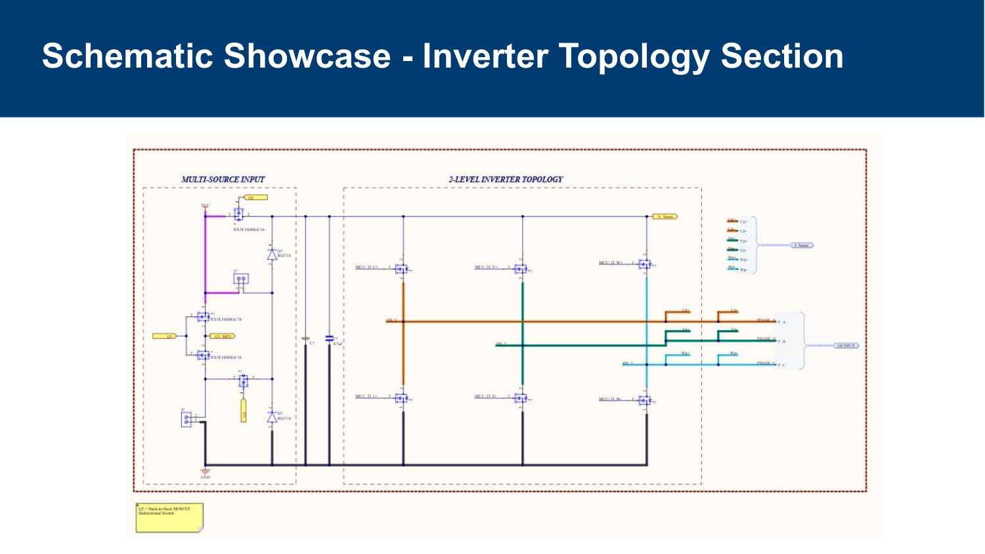
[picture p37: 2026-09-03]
assets/inverter-topology-schematic.png

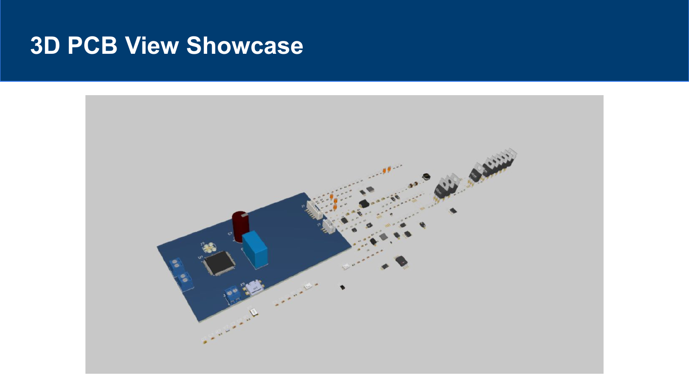
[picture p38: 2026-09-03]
assets/pcb-3d-view.png

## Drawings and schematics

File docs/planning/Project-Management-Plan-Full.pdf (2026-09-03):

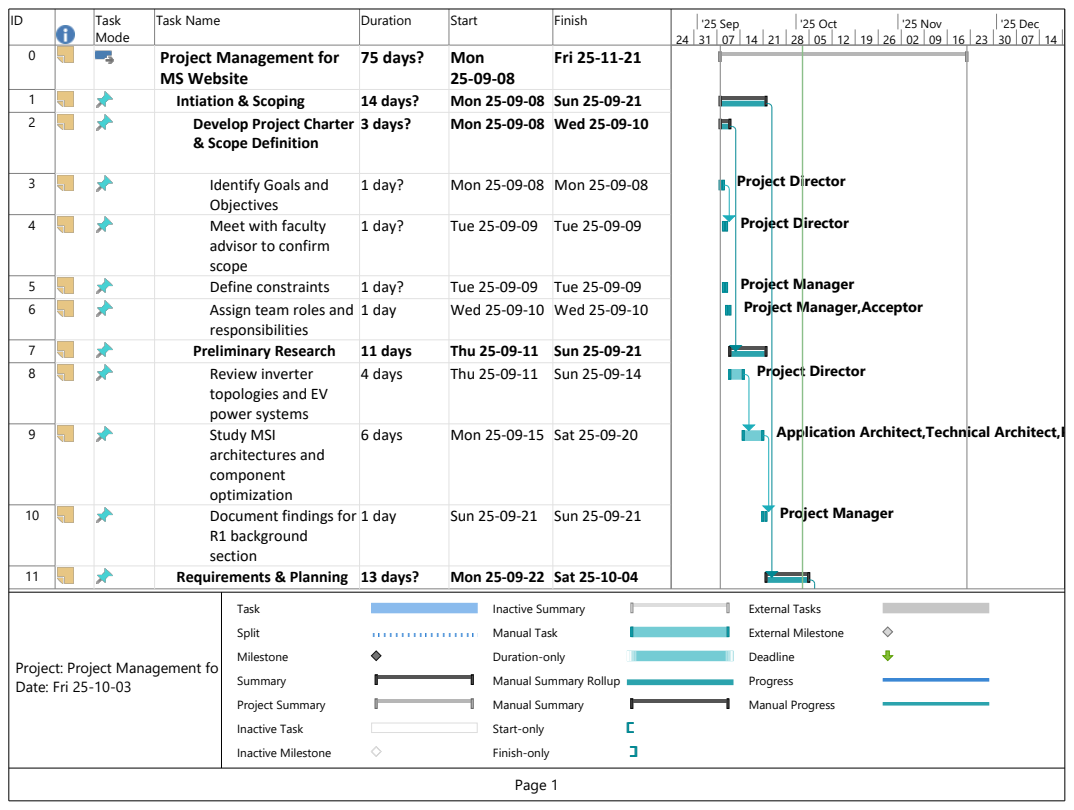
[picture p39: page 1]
Project Director; Project Manager; '25 Sep; '25 Oct; '25 Nov; '25 Dec; Task; Split; Milestone; Summary; Project Summary; Inactive Task; Inactive Milestone; Inactive Summary; Manual Task; Duration-only; Manual Summary; Start-only; Finish-only; External Tasks; External Milestone; Deadline; Progress; Manual Progress

ID | Task Mode | Task Name | Duration | Start | Finish

0 | | Project Management for MS Website | 75 days? | Mon 25-09-08 | Fri 25-11-21

1 | | Intiation & Scoping | 14 days? | Mon 25-09-08 | Sun 25-09-21
2 | | Develop Project Charter & Scope Definition | 3 days? | Mon 25-09-08 | Wed 25-09-10

3 | | Identify Goals and Objectives | 1 day? | Mon 25-09-08 | Mon 25-09-08

4 | | Meet with faculty advisor to confirm scope | 1 day? | Tue 25-09-09 | Tue 25-09-09

Project Manager
Project Manager,Acceptor

5 | | Define constraints | 1 day? | Tue 25-09-09 | Tue 25-09-09
6 | | Assign team roles and responsibilities | 1 day | Wed 25-09-10 | Wed 25-09-10

7 | | Preliminary Research | 11 days | Thu 25-09-11 | Sun 25-09-21
8 | | Review inverter topologies and EV power systems | 4 days | Thu 25-09-11 | Sun 25-09-14

9 | | Study MSI architectures and component optimization | 6 days | Mon 25-09-15 | Sat 25-09-20

Application Architect,Technical Architect,Project Manager

10 | | Document findings for R1 background section | 1 day | Sun 25-09-21 | Sun 25-09-21

11 | | Requirements & Planning | 13 days? | Mon 25-09-22 | Sat 25-10-04

Project: Project Management fo Date: Fri 25-10-03

Manual Summary Rollup

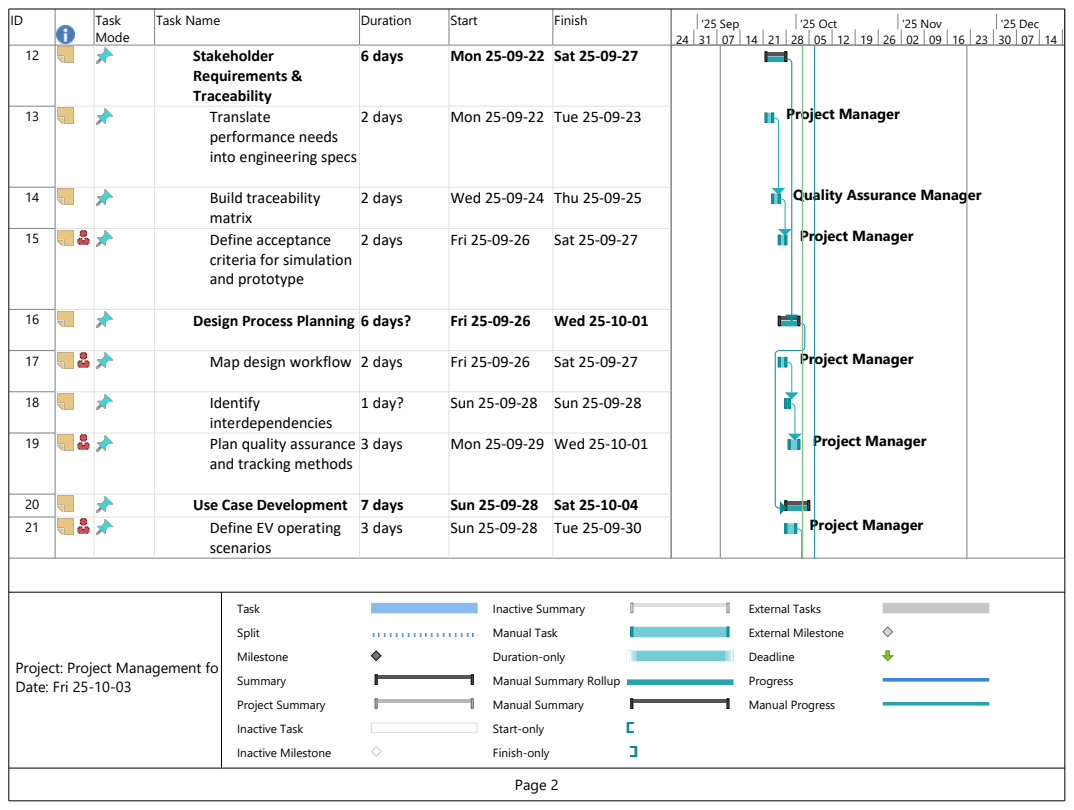
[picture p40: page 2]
Project Manager; Task; Split; Milestone; Summary; Project Summary; Inactive Task; Inactive Milestone; Inactive Summary; Manual Task; Duration-only; Manual Summary; Start-only; Finish-only; External Tasks; External Milestone; Deadline; Progress; Manual Progress

Mode

12 | | Stakeholder Requirements & Traceability | 6 days | Mon 25-09-22 | Sat 25-09-27

13 | | Translate performance needs into engineering specs | 2 days | Mon 25-09-22 | Tue 25-09-23

14 | | Build traceability matrix | 2 days | Wed 25-09-24 | Thu 25-09-25

Quality Assurance Manager

15 | | Define acceptance criteria for simulation and prototype | 2 days | Fri 25-09-26 | Sat 25-09-27

16 | | Design Process Planning | 6 days? | Fri 25-09-26 | Wed 25-10-01

17 | | Map design workflow | 2 days | Fri 25-09-26 | Sat 25-09-27

18 | | Identify interdependencies | 1 day? | Sun 25-09-28 | Sun 25-09-28

19 | | Plan quality assurance and tracking methods | 3 days | Mon 25-09-29 | Wed 25-10-01

20 | | Use Case Development | 7 days | Sun 25-09-28 | Sat 25-10-04
21 | | Define EV operating scenarios | 3 days | Sun 25-09-28 | Tue 25-09-30

Project: Project Management fo
Date: Fri 25-10-03

Manual Summary Rollup

| Mode
22 | | Create use cases for inverter behavior under different loads | 4 days | Wed 25-10-01 | Sat 25-10-04
23 | | Simulation & R1 Report | 6 days? | Sun 25-10-05 | Fri 25-10-10
24 | | PSIM Simulation Setup | 5 days | Sun 25-10-05 | Thu 25-10-09
25 | | Design initial MSI topology in PSIM | 4 days | Sun 25-10-05 | Wed 25-10-08
26 | | Run baseline simulations for voltage/current behavior | 1 day | Thu 25-10-09 | Thu 25-10-09
27 | | Analyze Switching Losses and Controllability | 3 days | Tue 25-10-07 | Thu 25-10-09
28 | | Evaluate switching losses | 3 days | Tue 25-10-07 | Thu 25-10-09
29 | | Assess controllability across performance range | 3 days | Tue 25-10-07 | Thu 25-10-09
30 | | R1 Report Finalization | 3 days? | Tue 25-10-07 | Fri 25-10-10
31 | | Compile all sections | 2 days | Wed 25-10-08 | Thu 25-10-09
32 | | Complete contribution matrix | 1 day | Fri 25-10-10 | Fri 25-10-10
33 | | Submission | 1 day? | Fri 25-10-10 | Fri 25-10-10

Project Manager

Project Director

Project Director

Project Manager
Project Manager

Project Manager

24 | 31 | 07 | 14 | 21 | 28 | 05 | 12 | 19 | 26 | 02 | 09 | 16 | 23 | 30 | 07 | 14

Task

Split

Milestone

Summary

Project Summary

Inactive Task

Inactive Milestone

Inactive Summary

Manual Task

Duration-only

Manual Summary Rollup

Manual Summary

Start-only

Finish-only

External Tasks

External Milestone

Deadline

Progress

Manual Progress

Project: Project Management fo Date: Fri 25-10-03
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

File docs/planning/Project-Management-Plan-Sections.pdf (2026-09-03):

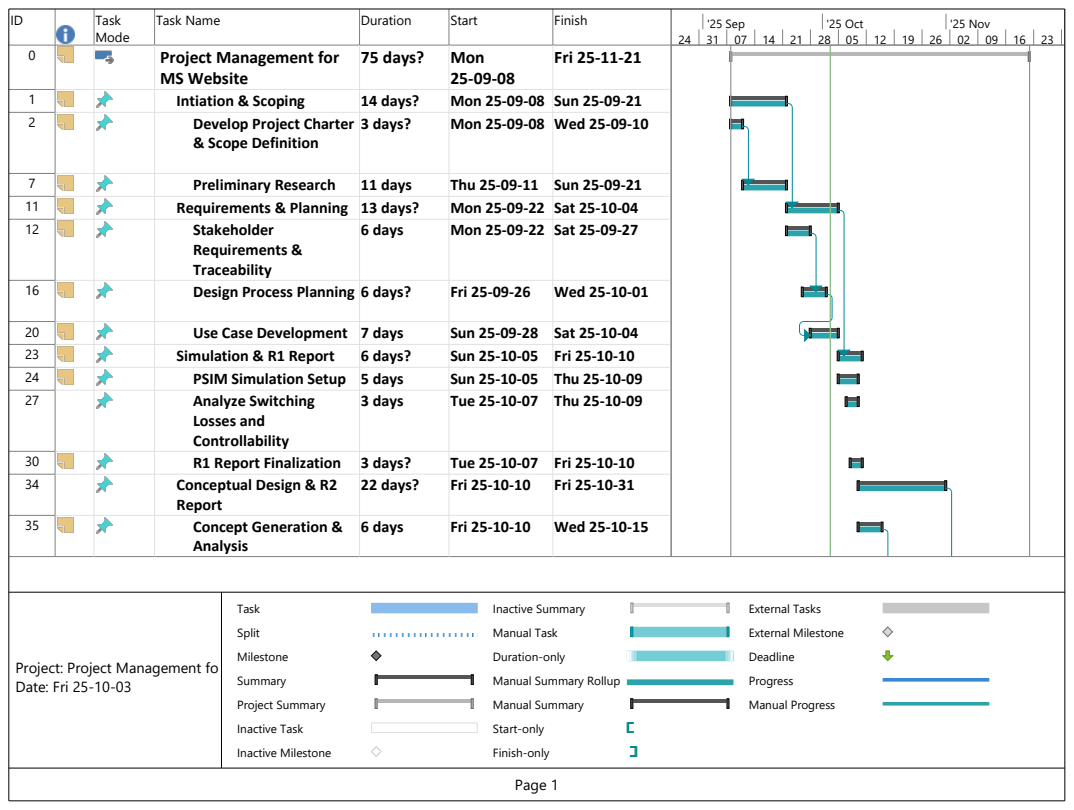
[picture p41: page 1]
'25 Sep; '25 Oct; '25 Nov; Task; Split; Milestone; Summary; Project Summary; Inactive Task; Inactive Milestone; Inactive Summary; Manual Task; Duration-only; Manual Summary; Start-only; Finish-only; External Tasks; External Milestone; Deadline; Progress; Manual Progress

ID | Task Mode | Task Name | Duration | Start | Finish

0 | | Project Management for MS Website | 75 days? | Mon 25-09-08 | Fri 25-11-21

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

7 | | Preliminary Research | 11 days | Thu 25-09-11 | Sun 25-09-21
11 | | Requirements & Planning | 13 days? | Mon 25-09-22 | Sat 25-10-04
12 | | Stakeholder Requirements & Traceability | 6 days | Mon 25-09-22 | Sat 25-09-27

16 | | Design Process Planning | 6 days? | Fri 25-09-26 | Wed 25-10-01

20 | | Use Case Development | 7 days | Sun 25-09-28 | Sat 25-10-04
23 | | Simulation & R1 Report | 6 days? | Sun 25-10-05 | Fri 25-10-10
24 | | PSIM Simulation Setup | 5 days | Sun 25-10-05 | Thu 25-10-09
27 | | Analyze Switching Losses and Controllability | 3 days | Tue 25-10-07 | Thu 25-10-09

30 | | R1 Report Finalization | 3 days? | Tue 25-10-07 | Fri 25-10-10
34 | | Conceptual Design & R2 Report | 22 days? | Fri 25-10-10 | Fri 25-10-31

35 | | Concept Generation & Analysis | 6 days | Fri 25-10-10 | Wed 25-10-15

Project: Project Management fo
Date: Fri 25-10-03

Manual Summary Rollup

ID | Task Mode | Task Name | Duration | Start | Finish
39 | | System Design Specification | 6 days | Thu 25-10-16 | Tue 25-10-21
43 | | Integration & Cost Estimation | 8 days? | Tue 25-10-21 | Wed 25-10-29
47 | | R2 Report Finalization | 2 days? | Thu 25-10-30 | Fri 25-10-31
50 | | Prototyping & Presentation21 days? | | Sat 25-11-01 | Fri 25-11-21
51 | | Hardware Prototype Development | 18 days | Sat 25-11-01 | Tue 25-11-18
55 | | Final Presentation & Demo | 3 days? | Wed 25-11-19 | Fri 25-11-21
24 | 31 | 07 | 14 | 21 | 28 | 05 | 12 | 19 | 26 | 02 | 09 | 16 | 23
'25 Sep | '25 Oct | '25 Nov

Task

Split

Milestone

Summary

Project Summary

Inactive Task

Inactive Milestone

Inactive Summary

Manual Task

Duration-only

Manual Summary Rollup

Manual Summary

Start-only

Finish-only

External Tasks

External Milestone

Deadline

Progress

Manual Progress

Project: Project Management fo Date: Fri 25-10-03

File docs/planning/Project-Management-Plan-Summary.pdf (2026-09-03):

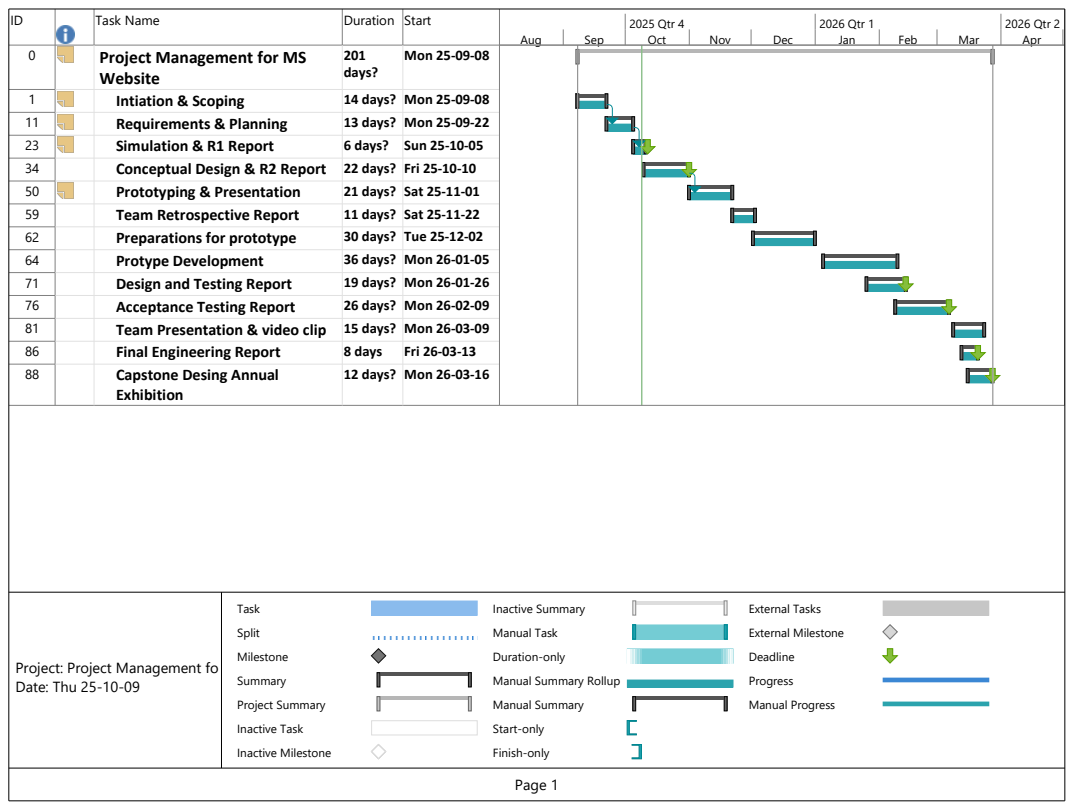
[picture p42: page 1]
Aug; Sep; Oct; Nov; Dec; Jan; Feb; Mar; Apr; 2025 Qtr 3; 2025 Qtr 4; 2026 Qtr 1; 2026 Qtr 2; Task; Split; Milestone; Summary; Project Summary; Inactive Task; Inactive Milestone; Inactive Summary; Manual Task; Duration-only; Manual Summary; Start-only; Finish-only; External Tasks; External Milestone; Deadline; Progress; Manual Progress

ID | Task Name | Duration | Start

0 | Project Management for MS Website | 201 days? | Mon 25-09-08

1 | Intiation & Scoping | 14 days? | Mon 25-09-08
11 | Requirements & Planning | 13 days? | Mon 25-09-22
23 | Simulation & R1 Report | 6 days? | Sun 25-10-05
34 | Conceptual Design & R2 Report | 22 days? | Fri 25-10-10
50 | Prototyping & Presentation | 21 days? | Sat 25-11-01
59 | Team Retrospective Report | 11 days? | Sat 25-11-22
62 | Preparations for prototype | 30 days? | Tue 25-12-02
64 | Protype Development | 36 days? | Mon 26-01-05
71 | Design and Testing Report | 19 days? | Mon 26-01-26
76 | Acceptance Testing Report | 26 days? | Mon 26-02-09
81 | Team Presentation & video clip | 15 days? | Mon 26-03-09
86 | Final Engineering Report | 8 days | Fri 26-03-13
88 | Capstone Desing Annual Exhibition | 12 days? | Mon 26-03-16

Project: Project Management fo
Date: Thu 25-10-09

Manual Summary Rollup
